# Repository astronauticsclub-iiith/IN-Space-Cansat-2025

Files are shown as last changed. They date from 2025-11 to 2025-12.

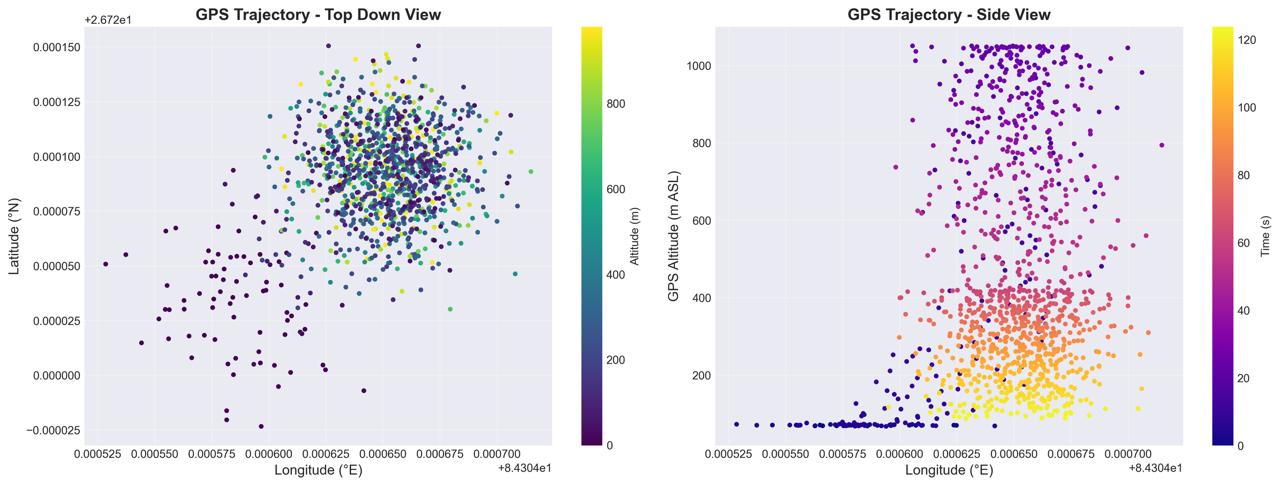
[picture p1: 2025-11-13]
Data-collected/WhatsApp Image 2025-11-07 at 16.43.02_4e6e8e08.jpg

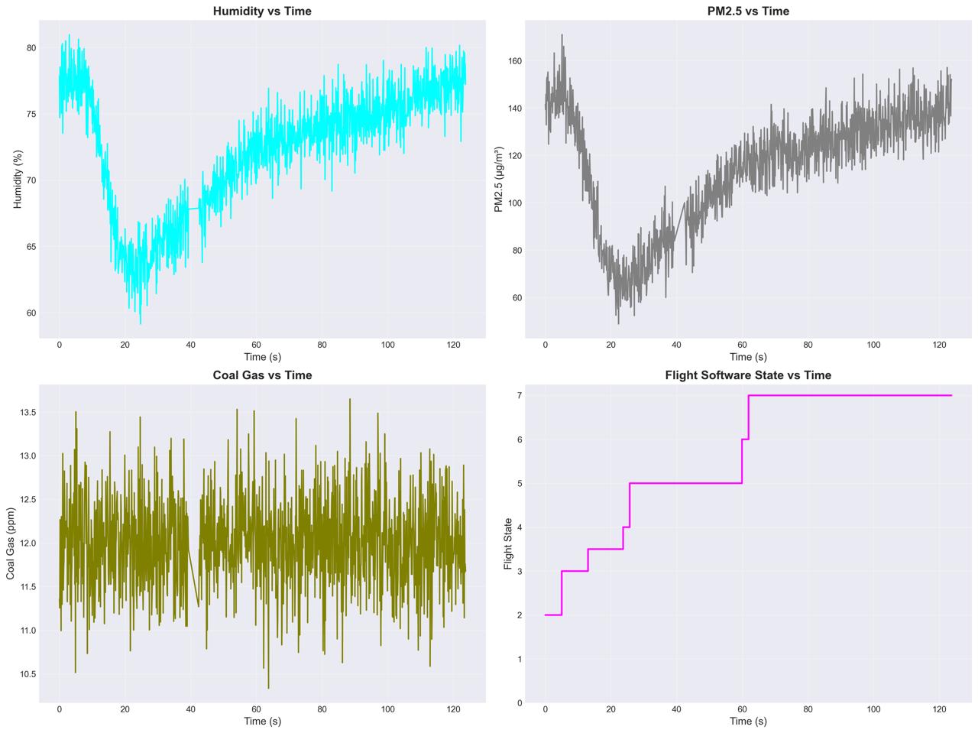
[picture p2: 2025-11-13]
Data-collected/WhatsApp Image 2025-11-07 at 16.43.02_c65afb3b.jpg

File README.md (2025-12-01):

## INSpace CanSat 24-25.

We have open-sourced our codefiles, 3D CAD models, PCB designs and simulation code for future teams participating in team in CanSat or anyone interested. The mission requirements for INSpace CanSat 24-25 be found [here](/Mission_Requirements). The directory structure is mostly self-explanatory.

**Team Name:** Team Brahmand (IIIT Hyderabad)

**Sponsors:** iHub Data (prototyping and development cost), IIIT Hyderabad (travel support)

**Advisor:** Prof Harikumar Kandath and Prof. Kavita Vemuri

**Members:** 
- Harsh Kapoor (Team Lead)
- Madhan Sai Krishna
- Vignesh Vembar
- Vijay Aravynthan S R
- Anushka Sharma
- Tejasvini Ramaswamy

**Additional Contributors:**
- Nav Singhal
- Kandagatla Akshith
- Tatva Agarwal
- Akshat Puneet
- Srinath Dhatre
- Bhaskar Itikela

**Mentors:** Members of Team Wanderlust (represented IIIT Hyderabad in US CanSat 23-24)

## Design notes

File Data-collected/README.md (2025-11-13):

# Data
Data collected during INSPACe CANSAT 2025, please refer to the following table for the units and details -

| **Parameter** | **Description** | **Unit** |
| --- | --- | --- |
| **Time** | Timestamp of the measurement | s |
| **Packet** | Telemetry packet count | — |
| **State** | System or flight state indicator | — |
| **Altitude** | Measured altitude (from barometric sensor) | m |
| **Pressure** | Atmospheric pressure | hPa |
| **Temperature (Barometric)** | Ambient temperature (from BMP sensor) | °C |
| **Temperature (DHT)** | Ambient temperature (from DHT sensor) | °C |
| **Humidity** | Relative humidity | % |
| **Voltage** | System/battery voltage | V |
| **GPS Latitude** | Latitude coordinate | ° |
| **GPS Longitude** | Longitude coordinate | ° |
| **GPS Altitude** | Altitude from GPS module | m |
| **Acceleration (X, Y, Z)** | Linear acceleration components | m/s² |
| **G-Force** | Resultant acceleration magnitude | g |
| **Gyro Rate** | Angular rate (from gyroscope) | °/s |
| **PM2.5** | Particulate matter concentration | µg/m³ |
| **CO (Coal Gas)** | Carbon monoxide concentration | ppm |

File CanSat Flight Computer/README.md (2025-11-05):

# CANSAT_ONBOARD_FINAL

- The CANSAT_ONBOARD_FINAL repository contains the complete flight software for the CanSat competition. This includes sensor integration, state management, telemetry transmission, command handling, data logging, and deployment mechanisms.
- Deployed on ESP32 microcontroller using FreeRTOS for real-time task management.
- Developed in C++ with modular architecture for Arduino IDE compatibility.

## Flows

### State diagram Flow (missing the SHT41)
```mermaid
graph LR
    subgraph Sensors ["Sensor Hardware"]
        LPS22[LPS22<br/>Barometer]
        BME680[BME680<br/>Environmental]
        ICM[ICM-20948<br/>9-DOF IMU]
        GPS[GPS Module<br/>GNSS]
        ADC[ADC<br/>Battery Voltage]
    end
    
    subgraph Processing ["Data Processing"]
        Fusion[Sensor Fusion<br/>Pressure & Temp]
        KF[Kalman Filter<br/>Altitude & Velocity]
        IMUCal[IMU Calibration<br/>Offset Removal]
        BattCalc[Battery %<br/>Calculator]
    end
    
    subgraph Output ["Data Output"]
        TelStruct[Telemetry<br/>Structure]
        CSV[CSV Format]
        LoRaTX[LoRa TX]
        SDLOG[SD Card Log]
    end
    
    LPS22 -->|Pressure, Temp| Fusion
    BME680 -->|Pressure, Temp,<br/>Humidity, Gas| Fusion
    
    Fusion -->|Fused Pressure| KF
    Fusion -->|Fused Temp| TelStruct
    BME680 -->|Humidity| TelStruct
    BME680 -->|Gas Resistance| TelStruct
    
    KF -->|Filtered Altitude| TelStruct
    KF -->|Vertical Velocity| TelStruct
    
    ICM -->|Raw Accel, Gyro| IMUCal
    IMUCal -->|Calibrated IMU| TelStruct
    
    GPS -->|Lat, Lon, Alt,<br/>Time, Sats| TelStruct
    GPS -->|GPS Alt| KF
    
    ADC -->|Raw Voltage| BattCalc
    BattCalc -->|Voltage, %| TelStruct
    
    TelStruct -->|Packet Data| CSV
    CSV -->|Formatted String| LoRaTX
    CSV -->|Formatted String| SDLOG
    
    style Sensors fill:#E8F4F8
    style Processing fill:#FFF4E6
    style Output fill:#E8F5E9
    
    style Fusion fill:#FFD54F
    style KF fill:#4FC3F7
    style IMUCal fill:#81C784
    style LoRaTX fill:#FF8A65
    style SDLOG fill:#BA68C8
```

---

### State Diagram (Syntax error)

```mermaid
stateDiagram-v2
    [*] --> BOOT: Power On
    
    BOOT --> LAUNCH_PAD: All Sensors OK
    BOOT --> BOOT: Waiting for Sensors
    
    LAUNCH_PAD --> TEST_MODE: "CMD: SET_MODE,TEST"
    TEST_MODE --> LAUNCH_PAD: "CMD: SET_MODE,FLIGHT"
    
    LAUNCH_PAD --> ASCENT: Launch Detected<br/>(Accel > 2.5g)
    
    ASCENT --> ROCKET_DEPLOY: Apogee Detected<br/>(V_vertical < -5 m/s)
    ASCENT --> ASCENT: Track Max Altitude
    
    ROCKET_DEPLOY --> DESCENT: Parachute Deployed<br/>(After 2 sec)
    
    DESCENT --> AEROBRAKE_RELEASE: Low Altitude<br/>(Alt < 50m)
    DESCENT --> IMPACT: Impact Detected<br/>(Alt < 5m, V < 2m/s)
    
    AEROBRAKE_RELEASE --> IMPACT: Impact Detected<br/>(Alt < 5m, V < 2m/s)
    
    IMPACT --> [*]: Mission Complete
    
    note right of BOOT
        Initialize all systems
        Load BlackBox state
        Check sensor health
    end note
    
    note right of LAUNCH_PAD
        Wait for launch
        Accept ground commands
        Continuous calibration available
    end note
    
    note right of TEST_MODE
        Manual testing mode
        Servo tests allowed
        No automatic transitions
    end note
    
    note right of ASCENT
        Record max altitude
        Monitor vertical velocity
        Prepare for apogee
    end note
    
    note right of ROCKET_DEPLOY
        Deploy parachute at apogee
        Log deployment event
        Save state to BlackBox
    end note
    
    note right of DESCENT
        Monitor altitude
        Check for release altitude
        Prepare for landing
    end note
    
    note right of AEROBRAKE_RELEASE
        Release aerobrake
        Continue descent monitoring
    end note
    
    note right of IMPACT
        Continue telemetry for recovery
        Reduce transmission rate
        Log GPS coordinates
    end note
```

---

### System Flowchart 
```mermaid
graph TB
    Start([Power On]) --> Init[Initialize System]
    Init --> I2C[Setup I2C Bus]
    I2C --> SPI[Setup SPI Bus]
    SPI --> InitSensors[Initialize Sensors]
    
    InitSensors --> CheckLPS{LPS22 OK?}
    CheckLPS -->|Yes| CheckBME{BME680 OK?}
    CheckLPS -->|No| LogLPSFail[Log LPS22 Failure]
    LogLPSFail --> CheckBME
    
    CheckBME -->|Yes| CheckIMU{ICM-20948 OK?}
    CheckBME -->|No| LogBMEFail[Log BME680 Failure]
    LogBMEFail --> CheckIMU
    
    CheckIMU -->|Yes| CheckLoRa{LoRa OK?}
    CheckIMU -->|No| LogIMUFail[Log IMU Failure]
    LogIMUFail --> CheckLoRa
    
    CheckLoRa -->|Yes| CheckGPS{GPS OK?}
    CheckLoRa -->|No| LogLoRaFail[Log LoRa Failure]
    LogLoRaFail --> CheckGPS
    
    CheckGPS -->|Yes| CheckServo{Servo OK?}
    CheckGPS -->|No| LogGPSFail[Log GPS Failure]
    LogGPSFail --> CheckServo
    
    CheckServo -->|Yes| CheckSD{SD Card OK?}
    CheckServo -->|No| LogServoFail[Log Servo Failure]
    LogServoFail --> CheckSD
    
    CheckSD -->|Yes| LoadState[BlackBox: Load Previous State]
    CheckSD -->|No| LogSDFail[Log SD Failure]
    LogSDFail --> LoadState
    
    LoadState --> RecoveryCheck{Valid Recovery Data?}
    RecoveryCheck -->|Yes| RecoverState[Recover Flight State]
    RecoveryCheck -->|No| FreshBoot[Fresh Boot Detected]
    
    RecoverState --> CreateTasks[Create RTOS Tasks]
    FreshBoot --> Calibrate[Calibrate Sensors]
    Calibrate --> CreateTasks
    
    CreateTasks --> Task1[Sensor Task - Core 0, P2]
    CreateTasks --> Task2[Telemetry Task - Core 0, P1]
    CreateTasks --> Task3[Command Task - Core 1, P1]
    CreateTasks --> Task4[State Machine Task - Core 1, P2]
    CreateTasks --> Task5[SD Writer Task - Core 0, P0]
    
    Task1 --> SensorLoop((Sensor Loop))
    Task2 --> TelemetryLoop((Telemetry Loop))
    Task3 --> CommandLoop((Command Loop))
    Task4 --> StateMachine((State Machine))
    Task5 --> SDLoop((SD Writer Loop))
    
    style Start fill:#90EE90
    style Init fill:#87CEEB
    style CreateTasks fill:#FFD700
    style SensorLoop fill:#FF6B6B
    style TelemetryLoop fill:#4ECDC4
    style CommandLoop fill:#95E1D3
    style StateMachine fill:#F38181
    style SDLoop fill:#AA96DA
```

---

# CANSAT Flight Software Requirements Specification

## 1. Functional Requirements

### 1.1 State Management (REQ-FSM)
- **REQ-FSM-001**: System SHALL maintain 8 distinct flight states: BOOT, TEST_MODE, LAUNCH_PAD, ASCENT, ROCKET_DEPLOY, DESCENT, AEROBRAKE_RELEASE, IMPACT
- **REQ-FSM-002**: Current state SHALL be transmitted in every telemetry packet
- **REQ-FSM-003**: System SHALL recover correct state after processor reset using sensor data
- **REQ-FSM-004**: State transitions SHALL be logged with timestamp
- **REQ-FSM-005**: Invalid state transitions SHALL be prevented

### 1.2 Telemetry Requirements (REQ-TM)
- **REQ-TM-001**: Telemetry SHALL be transmitted at 1 Hz minimum
- **REQ-TM-002**: Telemetry packet SHALL follow CSV format specified in competition rules
- **REQ-TM-003**: Telemetry SHALL include all 16 required fields: TEAM_ID, TIME_STAMPING, PACKET_COUNT, ALTITUDE, PRESSURE, TEMP, VOLTAGE, GNSS_TIME, GNSS_LATITUDE, GNSS_LONGITUDE, GNSS_ALTITUDE, GNSS_SATS, ACCEL_DATA, GYRO_DATA, FLIGHT_STATE, OPTIONAL_DATA
- **REQ-TM-004**: Time resolution SHALL be 1 second or better
- **REQ-TM-005**: Timestamp SHALL NOT be affected by processor reset
- **REQ-TM-006**: Packet count SHALL persist across resets
- **REQ-TM-007**: Altitude SHALL be relative to ground with 0.1m resolution
- **REQ-TM-008**: Pressure SHALL be in Pascals with 1 Pa resolution
- **REQ-TM-009**: Temperature SHALL be in Celsius with 0.1°C resolution
- **REQ-TM-010**: Voltage SHALL be in Volts with 0.01V resolution
- **REQ-TM-011**: GNSS coordinates SHALL have 0.0001 degree resolution
- **REQ-TM-012**: Accelerometer data SHALL be in m/s²
- **REQ-TM-013**: Gyroscope data SHALL be in deg/s
- **REQ-TM-014**: Optional data SHALL include battery percentage and vertical speed

### 1.3 Sensor Requirements (REQ-SENS)
- **REQ-SENS-001**: System SHALL read LPS22 barometer at 10 Hz minimum
- **REQ-SENS-002**: System SHALL read BME680 environmental sensor at 1 Hz minimum
- **REQ-SENS-003**: System SHALL read ICM-20948 IMU at 10 Hz minimum
- **REQ-SENS-004**: System SHALL read SHT41 temperature/humidity sensor at 1 Hz minimum
- **REQ-SENS-005**: System SHALL parse GPS data continuously without blocking
- **REQ-SENS-006**: Barometric altitude SHALL use sensor fusion from LPS22 and BME680
- **REQ-SENS-007**: Temperature SHALL use sensor fusion from LPS22 and BME680
- **REQ-SENS-008**: GPS altitude SHALL be used for cross-validation only
- **REQ-SENS-009**: Sensor failures SHALL be detected and logged
- **REQ-SENS-009**: System SHALL continue operating with degraded sensor suite
- **REQ-SENS-010**: Altitude SHALL be filtered using Kalman filter

### 1.4 Calibration Requirements (REQ-CAL)
- **REQ-CAL-001**: Ground altitude SHALL be calibrated before launch
- **REQ-CAL-002**: IMU gyroscope offsets SHALL be calibrated on launch pad
- **REQ-CAL-003**: Calibration SHALL use minimum 50 samples
- **REQ-CAL-004**: Calibration SHALL be triggerable via ground command
- **REQ-CAL-005**: Calibration results SHALL be logged

### 1.5 Command & Control Requirements (REQ-CMD)
- **REQ-CMD-001**: System SHALL receive commands via LoRa
- **REQ-CMD-002**: System SHALL support CAL_ALT command for altitude calibration
- **REQ-CMD-003**: System SHALL support CAL_IMU command for IMU calibration
- **REQ-CMD-004**: System SHALL support RESET_STATE command
- **REQ-CMD-005**: System SHALL support STATUS command for health check
- **REQ-CMD-006**: System SHALL support SET_MODE,TEST command
- **REQ-CMD-007**: System SHALL support SET_MODE,FLIGHT command
- **REQ-CMD-008**: System SHALL support TEST_SERVO command (ground only)
- **REQ-CMD-009**: System SHALL support DEPLOY_TEST command (ground only)
- **REQ-CMD-010**: System SHALL support START_TX/STOP_TX commands
- **REQ-CMD-011**: Unknown commands SHALL be rejected and logged
- **REQ-CMD-012**: Commands SHALL be processed within 100ms

### 1.6 Data Logging Requirements (REQ-LOG)
- **REQ-LOG-001**: All telemetry SHALL be logged to SD card
- **REQ-LOG-002**: All events SHALL be logged to separate event file
- **REQ-LOG-003**: Log files SHALL use CSV format
- **REQ-LOG-004**: Log files SHALL include headers
- **REQ-LOG-005**: Log filename SHALL include team ID and sequence number
- **REQ-LOG-006**: SD card writes SHALL be buffered to prevent data loss
- **REQ-LOG-007**: Buffers SHALL flush every 5 seconds
- **REQ-LOG-008**: System SHALL continue if SD card fails

### 1.7 Deployment Requirements (REQ-DEPLOY)
- **REQ-DEPLOY-001**: Parachute SHALL deploy at apogee detection
- **REQ-DEPLOY-002**: Apogee detection SHALL use vertical velocity < -5 m/s
- **REQ-DEPLOY-003**: Apogee detection SHALL require 3 seconds in ascent
- **REQ-DEPLOY-004**: Aerobrake SHALL release below 50m altitude
- **REQ-DEPLOY-005**: Deployment commands SHALL be mutex-protected
- **REQ-DEPLOY-006**: Deployment events SHALL be logged to BlackBox
- **REQ-DEPLOY-007**: Manual deployment SHALL only work on ground

### 1.8 Launch Detection Requirements (REQ-LAUNCH)
- **REQ-LAUNCH-001**: Launch SHALL be detected by acceleration > 2.5g
- **REQ-LAUNCH-002**: Launch detection SHALL require 2 seconds on pad
- **REQ-LAUNCH-003**: Launch event SHALL be logged
- **REQ-LAUNCH-004**: Launch SHALL transition to ASCENT state

### 1.9 Landing Detection Requirements (REQ-LAND)
- **REQ-LAND-001**: Landing SHALL be detected by altitude < 5m AGL
- **REQ-LAND-002**: Landing SHALL be detected by vertical speed < 2 m/s
- **REQ-LAND-003**: Landing detection SHALL require 10 seconds in descent
- **REQ-LAND-004**: Landing SHALL transition to IMPACT state
- **REQ-LAND-005**: Post-landing telemetry SHALL continue for recovery

### 1.10 Recovery Requirements (REQ-RECOVERY)
- **REQ-RECOVERY-001**: System SHALL save state to NVS every 5 seconds
- **REQ-RECOVERY-002**: System SHALL save state before critical operations
- **REQ-RECOVERY-003**: System SHALL load previous state on boot
- **REQ-RECOVERY-004**: System SHALL validate loaded state with magic number
- **REQ-RECOVERY-005**: System SHALL determine correct state from sensor data
- **REQ-RECOVERY-006**: Recovery SHALL be logged
- **REQ-RECOVERY-007**: Fresh boot SHALL be detected and logged

### 1.11 Safety Requirements (REQ-SAFE)
- **REQ-SAFE-001**: All SPI operations SHALL be mutex-protected
- **REQ-SAFE-002**: All servo operations SHALL be mutex-protected
- **REQ-SAFE-003**: All SD operations SHALL be mutex-protected
- **REQ-SAFE-004**: Battery voltage SHALL be monitored continuously
- **REQ-SAFE-005**: Low battery SHALL be logged (< 10%)
- **REQ-SAFE-006**: Sensor outliers SHALL be detected and rejected
- **REQ-SAFE-007**: Watchdog timer SHALL be implemented

## 2. Performance Requirements

### 2.1 Timing (REQ-PERF-TIME)
- **REQ-PERF-TIME-001**: Telemetry transmission SHALL occur every 1000ms ±50ms
- **REQ-PERF-TIME-002**: Sensor reading SHALL occur every 100ms ±10ms
- **REQ-PERF-TIME-003**: State machine SHALL execute every 100ms
- **REQ-PERF-TIME-004**: Command processing SHALL occur within 100ms
- **REQ-PERF-TIME-005**: Servo response SHALL occur within 200ms

### 2.2 Memory (REQ-PERF-MEM)
- **REQ-PERF-MEM-001**: Heap usage SHALL NOT exceed 80% of available
- **REQ-PERF-MEM-002**: Stack usage per task SHALL NOT exceed 4KB
- **REQ-PERF-MEM-003**: Telemetry buffer SHALL hold minimum 20 packets
- **REQ-PERF-MEM-004**: Event buffer SHALL hold minimum 20 events

### 2.3 Accuracy (REQ-PERF-ACC)
- **REQ-PERF-ACC-001**: Altitude accuracy SHALL be ±2m after filtering
- **REQ-PERF-ACC-002**: Vertical velocity accuracy SHALL be ±0.5 m/s
- **REQ-PERF-ACC-003**: Temperature fusion SHALL reduce noise by 50%
- **REQ-PERF-ACC-004**: Pressure fusion SHALL reduce noise by 40%

## 3. Interface Requirements

### 3.1 Hardware Interfaces (REQ-HW)
- **REQ-HW-001**: LPS22 SHALL communicate via I2C at address 0x5D
- **REQ-HW-002**: BME680 SHALL communicate via I2C at address 0x76
- **REQ-HW-003**: ICM-20948 SHALL communicate via I2C at address 0x69
- **REQ-HW-004**: LoRa SHALL use SPI with CS on GPIO 5
- **REQ-HW-005**: SD card SHALL use SPI with CS on GPIO 15
- **REQ-HW-006**: GPS SHALL use UART2 (RX:16, TX:17) at 9600 baud
- **REQ-HW-007**: Servo SHALL use PWM on GPIO 13
- **REQ-HW-008**: Battery voltage SHALL be read on GPIO 34 (ADC)

### 3.2 Communication Interfaces (REQ-COMM)
- **REQ-COMM-001**: LoRa SHALL operate at 433 MHz
- **REQ-COMM-002**: LoRa SHALL use spreading factor 7
- **REQ-COMM-003**: LoRa SHALL use bandwidth 125 kHz
- **REQ-COMM-004**: LoRa SHALL use coding rate 4/5
- **REQ-COMM-005**: LoRa SHALL enable CRC checking
- **REQ-COMM-006**: Serial debug SHALL operate at 115200 baud

## 4. Software Architecture Requirements

### 4.1 Task Structure (REQ-ARCH-TASK)
- **REQ-ARCH-TASK-001**: System SHALL use FreeRTOS
- **REQ-ARCH-TASK-002**: Sensor reading SHALL run on Core 0, Priority 2
- **REQ-ARCH-TASK-003**: Telemetry SHALL run on Core 0, Priority 1
- **REQ-ARCH-TASK-004**: Command processing SHALL run on Core 1, Priority 1
- **REQ-ARCH-TASK-005**: State machine SHALL run on Core 1, Priority 2
- **REQ-ARCH-TASK-006**: SD writing SHALL run on Core 0, Priority 0

### 4.2 Modularity (REQ-ARCH-MOD)
- **REQ-ARCH-MOD-001**: Configuration SHALL be in separate config.h
- **REQ-ARCH-MOD-002**: Sensor code SHALL be in sensors.h
- **REQ-ARCH-MOD-003**: Telemetry code SHALL be in Telemetry.h
- **REQ-ARCH-MOD-004**: State recovery SHALL be in BlackBox.h
- **REQ-ARCH-MOD-005**: Filtering SHALL be in KalmanFilter.h
- **REQ-ARCH-MOD-006**: Sensor fusion SHALL be in SensorFusion.h

## 5. Test Requirements

### 5.1 Unit Tests (REQ-TEST-UNIT)
- **REQ-TEST-UNIT-001**: Kalman filter SHALL be unit tested
- **REQ-TEST-UNIT-002**: Sensor fusion SHALL be unit tested
- **REQ-TEST-UNIT-003**: State transitions SHALL be unit tested
- **REQ-TEST-UNIT-004**: CSV formatting SHALL be unit tested
- **REQ-TEST-UNIT-005**: BlackBox recovery SHALL be unit tested

### 5.2 Integration Tests (REQ-TEST-INT)
- **REQ-TEST-INT-001**: All sensors SHALL be tested together
- **REQ-TEST-INT-002**: Command reception SHALL be tested
- **REQ-TEST-INT-003**: Telemetry transmission SHALL be tested
- **REQ-TEST-INT-004**: SD logging SHALL be tested
- **REQ-TEST-INT-005**: Servo control SHALL be tested

### 5.3 System Tests (REQ-TEST-SYS)
- **REQ-TEST-SYS-001**: Launch detection SHALL be tested in simulation
- **REQ-TEST-SYS-002**: Apogee detection SHALL be tested in simulation
- **REQ-TEST-SYS-003**: Landing detection SHALL be tested in simulation
- **REQ-TEST-SYS-004**: Reset recovery SHALL be tested
- **REQ-TEST-SYS-005**: Full flight profile SHALL be simulated

## 6. Compliance Requirements

### 6.1 Competition Rules (REQ-COMP)
- **REQ-COMP-001**: Telemetry format SHALL match competition specification exactly
- **REQ-COMP-002**: CSV file SHALL be named Flight_<TEAM_ID>.csv
- **REQ-COMP-003**: All required fields SHALL be present
- **REQ-COMP-004**: SI units SHALL be used for all measurements
- **REQ-COMP-005**: Ground station SHALL be able to parse telemetry

---

## Requirement Traceability Matrix

| Requirement ID | Verification Method | Test Case | Priority |
|---|---|---|---|
| REQ-FSM-001 | Code Review + Test | TC-001 | Critical |
| REQ-FSM-002 | Unit Test | TC-002 | Critical |
| REQ-FSM-003 | System Test | TC-003 | Critical |
| REQ-TM-001 | Timing Test | TC-004 | Critical |
| REQ-TM-002 | Format Test | TC-005 | Critical |
| REQ-SENS-001 | Performance Test | TC-006 | High |
| REQ-SENS-005 | Unit Test | TC-007 | High |
| REQ-CAL-001 | Integration Test | TC-008 | High |
| REQ-CMD-001 | Integration Test | TC-009 | High |
| REQ-LOG-001 | System Test | TC-010 | High |
| REQ-DEPLOY-001 | System Test | TC-011 | Critical |
| REQ-LAUNCH-001 | Simulation Test | TC-012 | Critical |
| REQ-LAND-001 | Simulation Test | TC-013 | Critical |
| REQ-RECOVERY-001 | System Test | TC-014 | Critical |
| REQ-SAFE-001 | Code Review | TC-015 | Critical |

---

## References 
Good playlist for FreeRTOS: https://www.youtube.com/watch?v=kP-pP6FEu8I&list=PLzvRQMJ9HDiQ3OIuBWCEW6yE0S0LUWhGU&index=20

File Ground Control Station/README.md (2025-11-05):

# GCS - By VA
# OLD VERSION (Don't use)
- new version is not public due to reasons 🙃
  
## Three main components
- Next js based 3d dashboard
- Fast API python program (reads from serial, saves data to csv and exposes an API endpoint for dashboard)
- ESP32 LoRa / Xbee parser

## Things to do 
- [x] Componentize the dashboard
- [x] Model replace ([3d convert] https://github.com/pmndrs/gltfjsx)
- [x] Serial read
- [x] CSV write
- [x] Faster updates
- [x] UI / UX improvements
- [x] Audio cues
- [x] Music ??? (After landing, what song?? Thunderstruck??)

## Images
### Dark Mode
GCS Dark

### Lite Mode
GCS Lite

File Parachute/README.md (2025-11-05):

# Backup-Parachute-System

A quad-redundant parachute deployment system for CanSat missions, designed to run on the Seeeduino XIAO (SAMD21).

## Overview

This system provides four independent deployment triggers to ensure reliable parachute deployment under various failure scenarios. Uses onboard clock and BMP280 pressure sensor for fault-tolerant operation.

## Hardware Requirements

- **Microcontroller:** Seeeduino XIAO SAMD21
- **Sensor:** Adafruit BMP280 (I2C address: 0x76)
- **Actuator:** Standard servo motor (connected to pin A1)
- **Power:** Appropriate power supply for XIAO and servo

## Wiring

| Component | Pin |
|---|-----|
| Servo Signal | A1 |
| BMP280 SDA | SDA (I2C) |
| BMP280 SCL | SCL (I2C) 


## Deployment Logic

The system uses a **quad-redundant trigger mechanism**. The first condition met triggers the servo to deploy the parachute.

### Deployment Triggers

1. **Primary: Altitude-Based Descent 🏔️**
   - **Condition:** After passing **500m**, deploys when altitude drops below **450m** for **5 consecutive readings**
   - **Purpose:** Primary deployment mechanism based on altitude thresholds
   - **Debounce:** 5 readings (1 second at 200ms sampling rate)

2. **Secondary: Post-Apogee Timer ⏱️**
   - **Condition:** Deploys **1 minute** after apogee (peak altitude) is detected
   - **Purpose:** Backup if altitude sensor fails during descent
   - **Detection:** Apogee detected when altitude drops 2m below maximum

3. **Tertiary: Master System Timer 🚨**
   - **Condition:** Deploys **30 seconds** after power-on (configurable to 10 minutes for flight)
   - **Purpose:** Ultimate failsafe for catastrophic failures
   - **Note:** Currently set to 30s for testing; change to `10 * 60 * 1000UL` for actual flight

4. **Quaternary: Emergency Low-Altitude Descent 🆘**
   - **Condition:** Descending for **>10 consecutive readings** while below **100m**
   - **Purpose:** Emergency deployment if stuck in tumbling descent at low altitude
   - **Reset:** Counter resets if altitude increases

## Features

- **Servo Self-Test:** On startup, servo sweeps full range (0° → 90° → 0°) to verify mechanical operation
- **Ground-Level Calibration:** Automatically calibrates pressure at startup for accurate altitude readings
- **Serial Debugging:** Real-time altitude, arming status, and timer information via Serial Monitor (9600 baud)
- **Single Deployment:** Prevents multiple deployments once triggered

## Installation

1. Install required libraries in Arduino IDE:
   ```
   - Adafruit BMP280 Library
   - Adafruit Unified Sensor
   - Servo (built-in)
   ```

2. Connect hardware according to wiring diagram

3. Upload code to Seeeduino XIAO

4. Open Serial Monitor (9600 baud) to view system status

## Configuration

### Key Parameters (adjust in code as needed)

```cpp
const float MIN_APOGEE_ALTITUDE = 500.0;        // Arming altitude (meters)
const float DEPLOYMENT_ALTITUDE = 450.0;        // Primary deployment altitude (meters)
const float EMERGENCY_LOW_ALTITUDE = 100.0;     // Emergency trigger altitude (meters)
const int DESCENT_READINGS_REQUIRED = 5;        // Debounce for primary trigger
const int EMERGENCY_DESCENT_READINGS = 10;      // Debounce for emergency trigger
const unsigned long APOGEE_TIMER_MS = 60000;    // Post-apogee timeout (1 minute)
const unsigned long MASTER_TIMER_MS = 30000;    // Master failsafe (30 sec for testing)
```

### Servo Angles

```cpp
const int SERVO_CLOSED_ANGLE = 0;   // Parachute locked
const int SERVO_OPEN_ANGLE = 90;    // Parachute deployed
```

## Testing

### Ground Test Mode
Current configuration deploys after 30 seconds for quick testing. Before flight:

**⚠️ CRITICAL: Change master timer back to 10 minutes:**
```cpp
const unsigned long MASTER_TIMER_MS = 10 * 60 * 1000UL;
```

### Expected Serial Output (Ground)
```
Alt: 0.1m, Max: 0.2m, Armed: 0, Master Time: 5s
Alt: 0.1m, Max: 0.2m, Armed: 0, Master Time: 6s
...
```

### Expected Serial Output (Flight)
```
Alt: 523.4m, Max: 523.4m, Armed: 1, Master Time: 45s
!!! APOGEE DETECTED - Starting 1-minute backup timer. !!!
Alt: 518.2m, Max: 523.4m, Armed: 1, Apogee Timer: 3s, Master Time: 48s
...
**************************************
DEPLOYING PARACHUTE! Reason: Altitude Trigger (Confirmed Descent)
**************************************
```

## Safety Notes

- Always test servo operation before flight
- Verify BMP280 sensor readings are stable
- Ensure backup battery is fully charged
- Test deployment mechanism separately before integration
- **Remember to adjust timer back to 10 minutes for actual flight**

## Troubleshooting

| Issue | Solution |
|---|---|
| Servo doesn't move | Check power supply, verify pin A1 connection |
| BMP280 not found | Verify I2C address (0x76 vs 0x77), check wiring |
| Deploys immediately | Check master timer value, verify startTime initialization |
| Altitude readings unstable | Sensor may need settling time, increase filter settings |

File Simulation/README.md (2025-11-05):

# CanSat-Simulation

- ROS 2 Humble + Gazebo (Classic, Fortress)  
- Mujoco  
- OpenFoam
- OpenRocket
- KiCAD

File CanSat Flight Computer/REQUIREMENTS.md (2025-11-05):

# CanSat Requirements Specification

## Overview
This document outlines the complete requirements for the CanSat flight software system, covering all functional, performance, safety, and interface requirements.

## Flight State Machine Requirements

### REQ-FSM-001: Flight States Definition
**Description:** The system shall implement exactly 8 flight states
**States:**
- BOOT = 0 (System initialization)
- TEST_MODE = 1 (Ground testing mode)  
- LAUNCH_PAD = 2 (Ready for launch)
- ASCENT = 3 (Rocket powered flight)
- ROCKET_DEPLOY = 4 (CanSat deployment from rocket)
- DESCENT = 5 (Parachute descent)
- AEROBRAKE_RELEASE = 6 (Aerobrake deployment)
- IMPACT = 7 (Ground contact and recovery)

## Telemetry Requirements

### REQ-TM-001: Transmission Rate
**Description:** Telemetry shall be transmitted at 1 Hz (once per second)
**Verification:** Check TELEMETRY_INTERVAL = 1000ms

### REQ-TM-002: CSV Format
**Description:** All telemetry shall use competition-specified CSV format
**Format:** TEAM_ID,TIME,PACKET_COUNT,ALTITUDE,PRESSURE,TEMP,VOLTAGE,GNSS_TIME,GNSS_LAT,GNSS_LON,GNSS_ALT,GNSS_SATS,ACCEL_DATA,GYRO_DATA,STATE,OPTIONAL_DATA

### REQ-TM-003: Required Fields
**Description:** All 16 telemetry fields must be present in every packet
1. TEAM_ID - Team identifier string
2. TIME_STAMPING - Mission elapsed time
3. PACKET_COUNT - Sequential packet number  
4. ALTITUDE - Pressure altitude (m)
5. PRESSURE - Atmospheric pressure (Pa)
6. TEMP - Temperature (°C)
7. VOLTAGE - Battery voltage (V)
8. GNSS_TIME - GPS time string
9. GNSS_LATITUDE - GPS latitude (degrees)
10. GNSS_LONGITUDE - GPS longitude (degrees) 
11. GNSS_ALTITUDE - GPS altitude (m)
12. GNSS_SATS - Number of GPS satellites
13. ACCELEROMETER_DATA - 3-axis acceleration
14. GYRO_SPIN_RATE - 3-axis gyro data
15. FLIGHT_SOFTWARE_STATE - Current flight state
16. OPTIONAL_DATA - Additional sensor data

### REQ-TM-008 to REQ-TM-013: Data Resolution
- **REQ-TM-008:** Altitude resolution: 0.1 meters
- **REQ-TM-009:** Pressure resolution: 1 Pa  
- **REQ-TM-010:** Temperature resolution: 0.1°C
- **REQ-TM-011:** Voltage resolution: 0.01V
- **REQ-TM-012:** GPS coordinate resolution: 0.0001 degrees
- **REQ-TM-013:** Time resolution: 0.1 seconds

## Sensor Requirements

### REQ-SENS-001: Pressure Sensors
**Description:** System shall use dual pressure sensors for redundancy
**Sensors:** LPS22HB primary, BME680 secondary

### REQ-SENS-002: IMU Requirements  
**Description:** 9-DOF IMU for attitude and acceleration
**Sensor:** ICM-20948 (3-axis accel, gyro, magnetometer)

### REQ-SENS-003: GPS Requirements
**Description:** GPS receiver for position and time
**Requirements:** Minimum 4 satellites for valid fix

### REQ-SENS-004: Environmental Sensors
**Description:** Temperature, humidity, gas resistance monitoring
**Sensor:** BME680 for environmental data

### REQ-SENS-005: Sensor Fusion
**Description:** Multiple sensors fused for improved accuracy
**Implementation:** Kalman filtering and sensor health monitoring

### REQ-SENS-006: Sensor Health Monitoring
**Description:** Continuous monitoring of sensor status
**Actions:** Automatic fallback to backup sensors

## Flight Detection Requirements

### REQ-LAUNCH-001: Launch Detection
**Description:** Detect rocket launch via acceleration threshold
**Threshold:** 2.5g sustained acceleration
**Duration:** Minimum 100ms above threshold

### REQ-DEPLOY-002: Apogee Detection  
**Description:** Detect CanSat deployment from rocket
**Method:** Vertical velocity < -5 m/s (descent initiated)
**Backup:** Altitude decrease over 3 consecutive readings

### REQ-LAND-001: Impact Detection - Altitude
**Description:** Detect ground impact via altitude threshold
**Threshold:** Below 5 meters AGL (Above Ground Level)

### REQ-LAND-002: Impact Detection - Velocity
**Description:** Confirm landing via low vertical velocity
**Threshold:** Vertical velocity < 2 m/s for 5 seconds

## Command Interface Requirements

### REQ-CMD-001 to REQ-CMD-010: Ground Commands
**Description:** System shall respond to ground station commands
**Commands:**
1. **CMD,CAL_ALT** - Calibrate ground altitude reference
2. **CMD,CAL_IMU** - Calibrate IMU sensors
3. **CMD,RESET_STATE** - Reset flight state to LAUNCH_PAD
4. **CMD,STATUS** - Report current system status
5. **CMD,SET_MODE,TEST** - Enter test mode
6. **CMD,SET_MODE,FLIGHT** - Enter flight mode  
7. **CMD,TEST_SERVO** - Test servo operation
8. **CMD,DEPLOY_TEST** - Test deployment mechanism
9. **CMD,START_TX** - Enable telemetry transmission
10. **CMD,STOP_TX** - Disable telemetry transmission

## Performance Requirements

### REQ-PERF-TIME-001: Telemetry Timing
**Description:** Telemetry transmitted every 1000ms ±50ms
**Jitter:** Maximum 5% timing deviation

### REQ-PERF-TIME-002: Sensor Reading Rate  
**Description:** Sensors read at 10 Hz (100ms intervals)
**Critical:** No missed sensor readings during flight

### REQ-PERF-MEM-001: Memory Usage
**Description:** Total firmware size < 80% of available flash
**Flash:** ESP32 4MB flash, firmware < 3.2MB
**RAM:** Runtime RAM usage < 70% of available

### REQ-PERF-POWER-001: Power Management
**Description:** System operational for minimum 3 hours
**Battery:** Monitor and report battery voltage
**Sleep:** Low-power modes when appropriate

## Safety Requirements

### REQ-SAFE-001: Dual Sensors
**Description:** Critical measurements use redundant sensors
**Implementation:** Primary/backup sensor pairs

### REQ-SAFE-002: Watchdog Timer
**Description:** Hardware watchdog prevents system lockup
**Timeout:** 5-second watchdog timer

### REQ-SAFE-003: Mutex Protection
**Description:** Shared resources protected by mutexes
**Resources:** SPI bus, I2C bus, SD card, servo control

### REQ-SAFE-004: Error Recovery
**Description:** System recovers from sensor failures
**Actions:** Automatic sensor switching, error logging

### REQ-SAFE-005: Deployment Safety
**Description:** Parachute deployment only in valid states
**States:** Only deploy in DESCENT or AEROBRAKE_RELEASE

## Recovery Requirements

### REQ-RECOVERY-001: BlackBox Logging
**Description:** All critical events logged to non-volatile storage
**Storage:** SD card with backup to EEPROM
**Data:** Flight state changes, sensor failures, commands

### REQ-RECOVERY-002: State Persistence
**Description:** Flight state preserved across power cycles
**Implementation:** State saved to EEPROM every transition
**Recovery:** Automatic state recovery on boot

### REQ-RECOVERY-003: Data Integrity
**Description:** Logged data protected against corruption
**Methods:** Checksums, magic numbers, redundant storage

## Architecture Requirements

### REQ-ARCH-MOD: Modular Design
**Description:** Software organized in functional modules
**Modules:** Config, Sensors, Telemetry, BlackBox, KalmanFilter, SensorFusion, DataBuffer

### REQ-ARCH-TASK: RTOS Task Structure
**Description:** FreeRTOS tasks for concurrent operation
**Tasks:**
- sensorTask (Core 0) - Sensor data collection
- telemetryTask (Core 1) - Data transmission  
- commandTask (Core 1) - Command processing
- stateTask (Core 0) - State machine management
- sdTask (Core 0) - Data logging

### REQ-ARCH-CORE: Dual Core Usage
**Description:** Utilize both ESP32 cores efficiently  
**Core 0:** Time-critical sensor and control tasks
**Core 1:** Communication and data processing

## Hardware Interface Requirements

### REQ-HW-001 to REQ-HW-005: Pin Assignments
**Description:** Standardized pin assignments for hardware interfaces
**Pins:**
- LORA_SS_PIN = 5 (LoRa SPI select)
- GPS_RX_PIN = 16, GPS_TX_PIN = 17 (GPS UART)
- SERVO_PIN = 13 (Parachute servo control)
- VOLTAGE_PIN = 34 (Battery voltage ADC)
- SD_CS_PIN = 15 (SD card SPI select)

### REQ-HW-I2C: I2C Bus Configuration
**Description:** I2C sensors on shared bus with proper addressing
**Addresses:** LPS22=0x5D, BME680=0x76, ICM=0x69, OLED=0x3C

### REQ-HW-SPI: SPI Bus Configuration  
**Description:** SPI devices with proper chip select management
**Devices:** LoRa radio, SD card (separate CS pins)

## Verification Methods
- **Static Analysis:** Code inspection and automated checks
- **Unit Testing:** Individual module testing with mocks
- **Integration Testing:** Module interaction validation  
- **Hardware-in-Loop:** Testing with actual sensors
- **Flight Simulation:** Complete mission scenario testing
- **Ground Testing:** Pre-flight validation procedures

## Compliance Matrix
All requirements are traceable to:
- Competition rules and regulations
- Safety standards and best practices  
- Hardware capabilities and constraints
- Mission success criteria

---
**Document Version:** 1.0
**Last Updated:** October 2025
**Approved By:** Team Brahmand

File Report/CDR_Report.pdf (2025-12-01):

# INDEX

## 4. Systems Overview | 4-10

## 5. Mechanical Subsystem | 11-18

## 6. Communications & Data Handling Subsystem | 19-33

## 7. Sensor Subsystem | 34-70

## 8. Actuator Subsystem | 71-72

## 9. Payload/Gyroscope Subsystem | 73-77

## 10. Descent Control Subsystem | 78-79

## 11. Electrical Power Subsystem | 80 - 85

## 12. Flight Software & Ground Control Software Subsystem | 86 - 98

## 13. Mission Operation & Analysis | 99 - 106

## 14. Management & Logistics | 107 - 119

# 1 Introduction

The INSPACe CANSAT Competition serves as a platform for aspiring engineers, scientists, and space enthusiasts to apply

their technical knowledge in a practical, real-world aerospace challenge. This competition fosters innovation, collaboration, and

problem-solving by tasking teams with designing, building, and launching a miniature satellite, or CANSAT, to meet a set of

mission objectives.

This Complete Design Review (CDR) Document encapsulates our team’s design, development, and testing processes. It

serves as a comprehensive record of our mission objectives, system architecture, payload design, electronics integration, software

development, and flight readiness. The document also details the challenges encountered, the solutions implemented, and the

validation methods used to ensure a successful mission.

Our approach to the CANSAT design prioritizes functionality, reliability, and innovation while adhering to the competition

guidelines. Each subsystem has been meticulously designed and tested to ensure optimal performance in the demanding conditions

of launch and recovery. Additionally, we have emphasized teamwork and interdisciplinary collaboration, ensuring that our final

product is a well-engineered solution that meets the expectations of the competition.

Through this journey, we have gained invaluable insights into aerospace engineering, mission planning, and systems engi-

neering. This document not only reflects our technical expertise but also showcases our passion for space exploration and our

commitment to learning. We look forward to contributing to the broader scientific community and leveraging this experience

for future advancements in aerospace technology.

Regards,

Team Brahmand,

IIIT-Hyderabad

# 2 Team Description

# 3 List of Acronyms

Acronym | Full Form | Acronym | Full Form
CANSAT | Can Satellite | INSPACe | Indian National Space Promotion and Authorization Center
GPS | Global Positioning System | IMU | Inertial Measurement Unit
PCB | Printed Circuit Board | RF | Radio Frequency
ADC | Analog to Digital Converter | MCU | Microcontroller Unit
PWM | Pulse Width Modulation | ISP | In-System Programming
FSW | Flight Software | GCS | Ground Control Station
LEO | Low Earth Orbit | EMI | Electromagnetic Interference
RCS | Reaction Control System | SLA | Stereo Lithography Apparatus
CONOPS | Concept of Operations | VHF | Very High Frequency
Li-Po | Lithium Polymer (Battery) | ESC | Electronic Speed Controller
A | Ampere | m | meter
°C | Celsius | mA | Milli-Ampere
dBi | decibel | mm | milli meter
g | Acceleration due to gravity | mW | milli Watt
G | G-force | MB | Mega Byte
GHz | Giga-Hertz | MHz | Mega-Hertz
h | hour | µA | Micro-Ampere
hPa | hecta Pascal | N | Newton
Hz | Hertz | Pa | Pascal
km | kilometer | s | second
kPa | Kilo Pascal | V | Volt
KB | Kilo Byte | Kg | Kilo gram

Table 1: Abbreviations and their Full Forms

# 4 Systems Overview

## 4.1 Mission Summary

The following tables lists all the Objectives of the INSPACe CANSAT Competition, 2024-2025.

Main Objectives

Design an “Innovative Mechanical Gyro-control” system that shall demonstrate the descent control of

the CANSAT

1. Weight and Cost Design: | The CanSat shall have a mass of 1000 +/- 50 grams, meet specific dimensional requirements and survive structural and environmental forces. Ensure the cost remains under 1,00,000 rs.
2. Dimensions: | CanSat shall fit in a cylinder of 0.15m diameter and 0.40m height and have tolerances to ensure deploy-ment from rocket fairing.
3. Gyroscope: | CanSat shall stabilize itself during the descent using the Mechanical Gyroscopes.
4. Structural Integrity: | CanSat structure shall be built to survive 15 Gs of launch acceleration & 30 Gs of shock. All electronics shall be enclosed and shielded from the environment. No electronics can be exposed except for sensors. There must be a structural enclosure.
5. Electronics and Telemetry: | The CanSat shall continuously sense and transmit a variety of sensory data from launch and stop this transmission upon landing.
6. Ground Station and Flight Software: | Develop a ground station that calibrates altitude, generates CSV files, and displays telemetry in real-time during descent. The software must also implement a ”Simulation mode”.

Bonus Objectives

1. Novel descent trajectory Control, Innovative materials.
2. Additional Innovative Sensors and Communication Systems.
3. Provision of video capture from separation till final touchdown.
4. Innovative recovery techniques viz. HAM radio/Advanced beacons.
5. Innovative Quality and reliability analysis methodologies.

## 4.2 CONOPS

Sr. No. | Event | Altitude | Description
1. | Separation from Rocket | 1000 m | The CanSat is ejected from the rocket.
2. | Drogue chute Deployment | 1000 m | The drogue parachute is deployed, descent rate 17 m/s.
3. | Descent by Drogue chute | 1000 - 500 m | Descent by drogue chute and Gyroscope mechanism stabal-izes the CANSAT.
4. | Main chute Deployment | 500 m | Main parachute deploys, descent rate reduces to 2m/s
5. | Descent and Data Collection | 500 – 100 m | The onboard systems actively gather and store data, and potentially transmit it to ground control.
6. | Landing leg deployment | 100 m | The landing legs are deployed, and the CanSat’s Active Gyro Control mechanism enters high power mode
7. | Landing and recovery | 0 m | CanSat lands safely and is recovered

## 4.3 System Level Requirements Compliance

Req. No. | Requirements | Compliance
1. | Total mass of the CANSAT shall be under 1000gm (+/- 50 gm). | Comply
2. | CANSAT shall fit in a cylindrical body of 0.15 m diameter x 0.40 m height. Tolerances are to be included to facilitate container deployment from the rocket fairing. | Comply
3. | Any sharp edges on the container body shall be avoided as it can cause interference during the CANSAT ejection from the rocket. | Comply
4. | Colour of the CANSAT body shall be fluorescent i.e., pink, red or orange, and shall embody the Indian flag. | Comply
5. | Rocket Airframe will not be allowed to be used as a part of any CANSAT operation. | Comply
6. | The CANSAT shall consist of necessary sensors to provide the following mandatory Real-time datasets: Position data, altitude, pressure, temperature, orientation data, power data & system status. | Comply
7. | Each data field shall be displayed in real-time on the ground station user interface/software. | Comply
8. | CANSAT shall also record the data and save it into an onboard SD card in case of telemetry connection loss. | Comply
9. | All electronics shall be enclosed and shielded from the environment. No electronics can be exposed except for sensors. There must be a structural enclosure. | Comply
10. | CANSAT structure shall be built to survive 15 Gs of launch acceleration & 30 Gs of shock. | Comply
11. | Electronic circuit boards must be hard mounted using proper mounts such as standoffs and screws. High-performance adhesives can also be used. | Comply
12. | Team number, email address and phone number must be placed on the structure in English, Hindi and the Regional language of the launch state to aid in recovery. | Comply
13. | An audio beacon shall be installed on CANSAT as a recovery assist. It may be powered after landing or operate continuously. The audio beacon must have a minimum sound pressure level of 92 dB, unobstructed. | Comply
14. | The CANSAT shall have an external power switch with an indicator light or sound for being turned on or off, in order to avoid the de-assembling of CANSATs on the launch pad. | Comply
15. | The CANSAT shall have a battery capacity to support up to 2 hours of wait in on the launch pad with additional time for flight operations. | Comply
16. | Spring contacts shall not be used for making electrical connections to batteries. | Comply

17. | The battery source may be alkaline, Ni-Cad, Ni-MH or Lithium ion. Lithium polymer batteries are not allowed. Lithium cells must be manufactured with a metal package similar to 18650 cells. | Comply
18. | An easily accessible battery compartment must be included allowing batteries to be installed or removed in less than a minute and not require total disassembly of the CANSAT. | Comply
19. | The CANSAT shall contain a total of 2 descent control mechanisms, to be used at different stages while descent. | Comply
20. | CANSAT shall immediately deploy the first parachute after ejection from the rocket. | Comply
21. | The first parachute shall be connected to the outer body of the CANSAT and no ejection mechanism shall be attached to it. | Comply
22. | The descent rate of the 1st parachute shall be 20 m/s +/- 5m/s. | Comply
23. | The second descent control mechanism shall open at an altitude of 500m (+/-10 m) to further decrease the descent rate of the CANSAT to 1 to 3m/s. | Comply
24. | The descent control system shall not use any hazardous chemical-based explosive or pyrotechnic devices. However, green propulsion is allowed if being used under the same weight constraint. | Comply
25. | CANSAT shall stabilize itself during the descent using the mechanical gyro mechanism. | Comply
26. | The CANSAT communications radio shall be the XBEE radio series 1/2/pro. | Comply
27. | The XBEE radios shall have their NETID/PANID set to the team number. | Comply
28. | The XBEE radio shall not use the broadcast mode. | Comply
29. | The XBEE radio can operate in any mode as long as it does not interfere with other XBEE radios. | Comply
30. | Each team shall develop and use their own ground station. All telemetry shall be displayed in real-time during launch and descent. All telemetry shall be displayed in engineering units (meters, meters per second, Celsius, etc.). Teams shall plot data in real-time during flight. | Comply

## 4.4 Changes/Modifications done from PDR round

Sub-System | Change | Rationale
Mechanical | Rod & Plate Interfacing: Larger diameter car-bon fiber rods instead of stacks. Landing Mechanism: Landing legs instead of crush core. Section Dividers: Modified plate geometry. Gyro: Split into two sections. Nichrome Wire: Added for deploying landing legs. | Better support, reduced mass, improved de-sign. More stable and reliable landing. More reliable design to hold outer shield of CanSat. Larger diameter, efficient use of space. Reliable and robust design.
Descent Control | Parachutes sizing changed Slight changes in deployment mechanism | For added reliability and robustness For easier and smoother parachute deploy-ment
CDH | Rod-type antenna replaced with a sticker-type antenna. RTC module replaced. Using 2 Raspberry Pis instead of 1. | Mass reduction, better suited for structure. Availability. Redundancy, extra CSI port for bonus camera.
EPS | Battery changed. | Weight reduction.
FSW | Sampling rate changed from 25Hz to 10Hz. Partially integrated two cameras in flight soft-ware. Backup processor added. Logic changes. | Reduces compute load. Bonus task undertaken. Fallback safety in case of reset. Increased precision.
GCS | GCS antenna changed. Interactive dashboard added. | Cost cutting while maintaining performance. Easy to observe incoming data.

## 4.5 Physical Layout & Dimensions

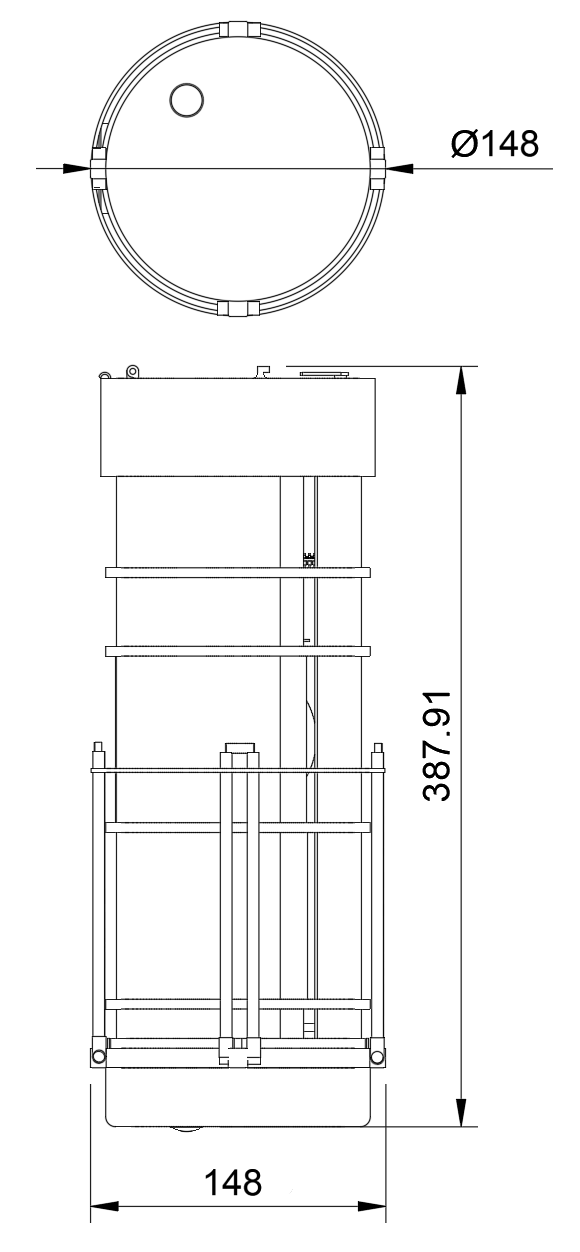
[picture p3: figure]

Figure 1: Physical Layout

Dimensions | Mission Requirements | CAD Models | Margins
Diameter | 0.15m | 0.148m | 0.002m
Height | 0.40m | 0.387m | 0.013m

### 4.6 Color Coding Scheme of CANSAT

Sr No | Parts/Location | Colour | Reasoning
1. | Outer Casing | Saffron, White, Green | Enhanced Visibility and Ease of track-ing during Descent and Recovery
2. | Electronics and Electricals | Fluorescent Green | Ease of Locating by Visual Inspection
3. | First Parachute | Fluorescent Pink | Mission Requirement and Ease of Tracking
4. | Second Parachute | Fluorescent Red | Mission Requirement and Ease of Tracking
5. | Gyroscope and Other Mechanical Components | Grey, White | Ease of Locating by Visual Inspection
6. | Lower Shell | Transparent | Required for Video Recording
7. | Structural Elements | Black | Ease of Locating by Visual Inspection

# 5 Mechanical Subsystem

### 5.1 Mechanical Subsystem Overview

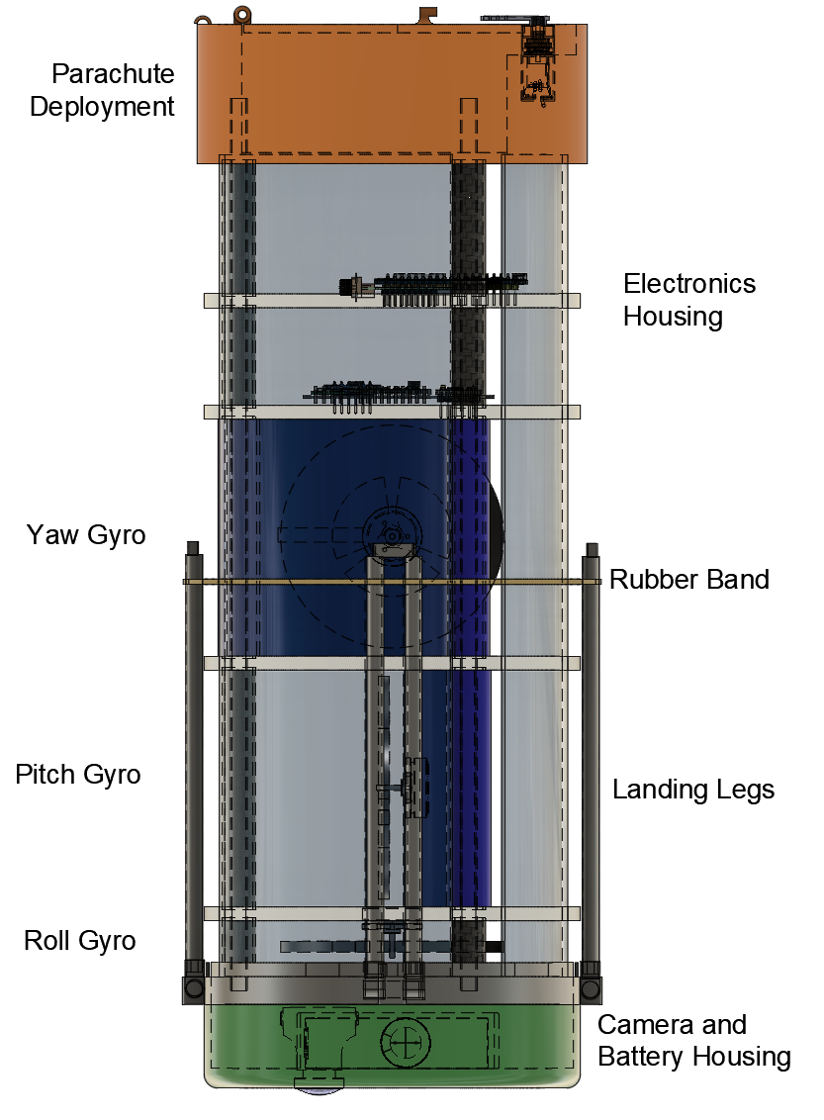
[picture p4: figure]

Figure 2: Cansat Structure

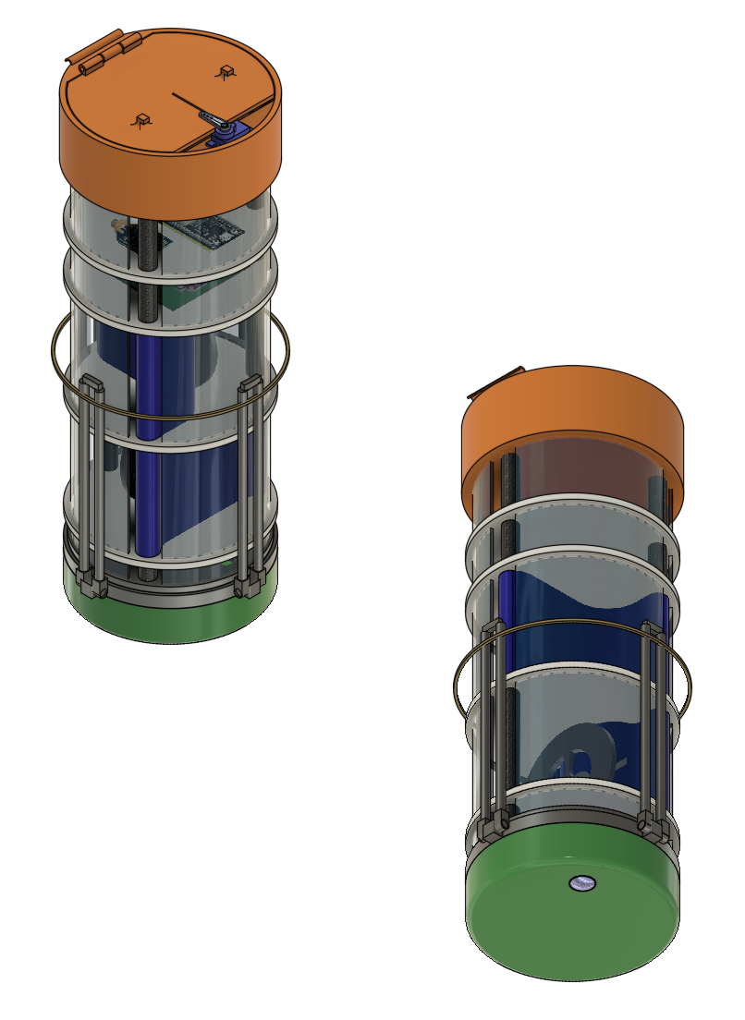
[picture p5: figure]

Figure 3: Isometric View of Cansat Structure

### 5.2 Materials Selection

Materials Selection

Component | Material | Pros | Cons | Rationale
Outer Covering | Plastic mesh | Lightweight | Bendable and might bend | To conserve weight, aid aerodynamic stability
Rods (Structural Support & Spacer) | Carbon Fiber | High Load bearing capacity | Relatively expen-sive | Needed for structural in-tegrity under load
Parachute | Nylon Rip-stop Fabric | Proven reliability | Bulkier when packed | Ensures controlled descent
Landing Legs | Carbon fiber | Easy to procure | Expensive, Brittle | absorbs shock during landing
Fasteners | Steel Screws | High strength | Adds to overall weight | Essential for secure con-nections

### 5.3 Changes Since PDR

- The previous stack design for the main structure proved to be very heavy. So, we moved to a simpler design that uses

carbon fibre rods as spacers.

- The chosen landing structure was a Crush Core, but upon further consideration we decided to use a Landing Leg system

that would be much more reliable.

- The plate design was changed from having protrusions to just have slits that the outer cover can slide into. This gives the

outer cover more stability.

### 5.4 CanSat Body

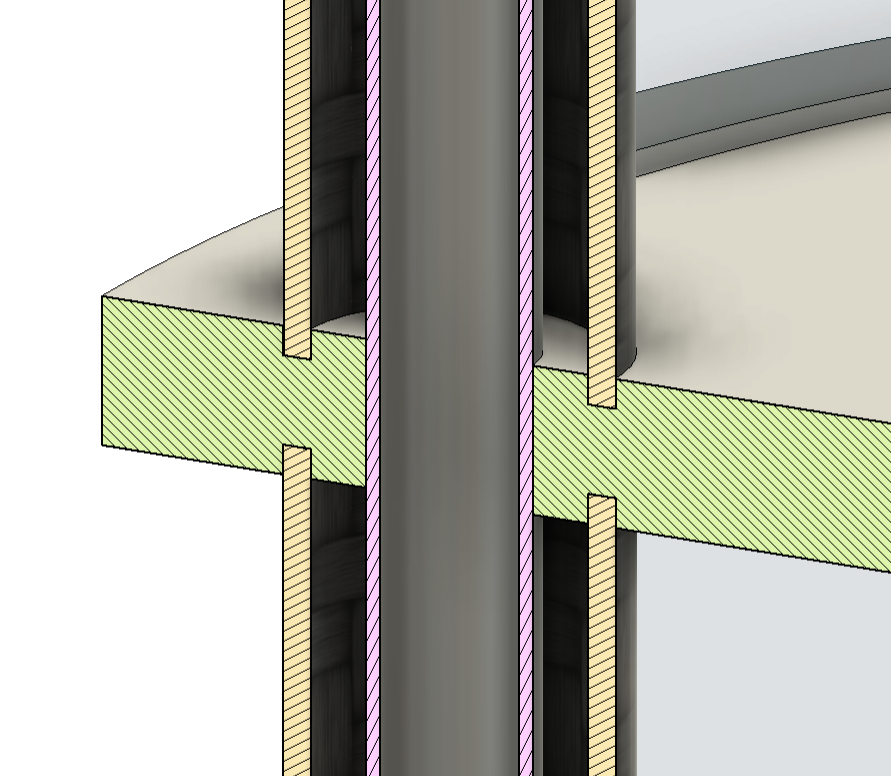
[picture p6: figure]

(a) Spacer Design for Plates | (b) Top View

Figure 4: Structure Details

The main structural integrity of the cansat is provided by three carbon fiber rods that go throughout it. There are plates made

to hold the components that have slots to add thicker carbon fiber rods. These add more structural integrity and also help to

keep the plates in place. The outer cover is made using plastic mesh that will be slotted in throughout the cansat.

### 5.5 Parachute Container

(a) Before Deployment | (b) After Deployment

Figure 5: Deployment Mechanism

The parachute container is held close by a servo motor. There is also a rubber band which tensions the lid to open. When the

servo swivels out of the way, the lid opens and the secondary parachute is deployed.

### 5.6 Landing Subsystem

The landing subsystem is responsible for ensuring that the cansat has a stable and controlled touchdown. As the terrain is

expected to be predominantly rocky and the launch will take place in a wide open area, our landing system must be able to cope

with those conditions.

Figure 6: Strut-Based Landing Gear

The strut-based landing gear system consists of foldable legs that remain

stowed during launch and the initial descent phase. These legs are secured

using nichrome wire, which is severed when the CanSat reaches an altitude

of 250 meters, triggering the deployment of the landing legs.

Key Features:

- The legs are tensioned downward using rubber bands, ensuring they

deploy in the correct orientation.

- Carbon fiber components, combined with the cushioning effect of the

rubber bands, help absorb impact forces.

- Compact storage allows better space utilization for sensors and cam-

eras.

(a) Landing Legs Undeployed | (b) Landing Legs Open

Figure 7: Landing Legs

Figure 8: Battery Compartment and Camera

### 5.7 Base Plate and Battery Compartment

The base plate features compartments designed to securely hold the battery cells. It also includes a cutout at the bottom to

accommodate the camera lens. Additionally, portions of the power circuitry are housed within this section. The main structural

rods will be firmly anchored to this base, ensuring stability and support.

### 5.8 Parachute Testing

We tested our parachute system using a mass simulator. The parachute has a diameter of 120 cm and a spill hole of 12 cm,

designed to ensure a controlled descent during CanSat deployment.

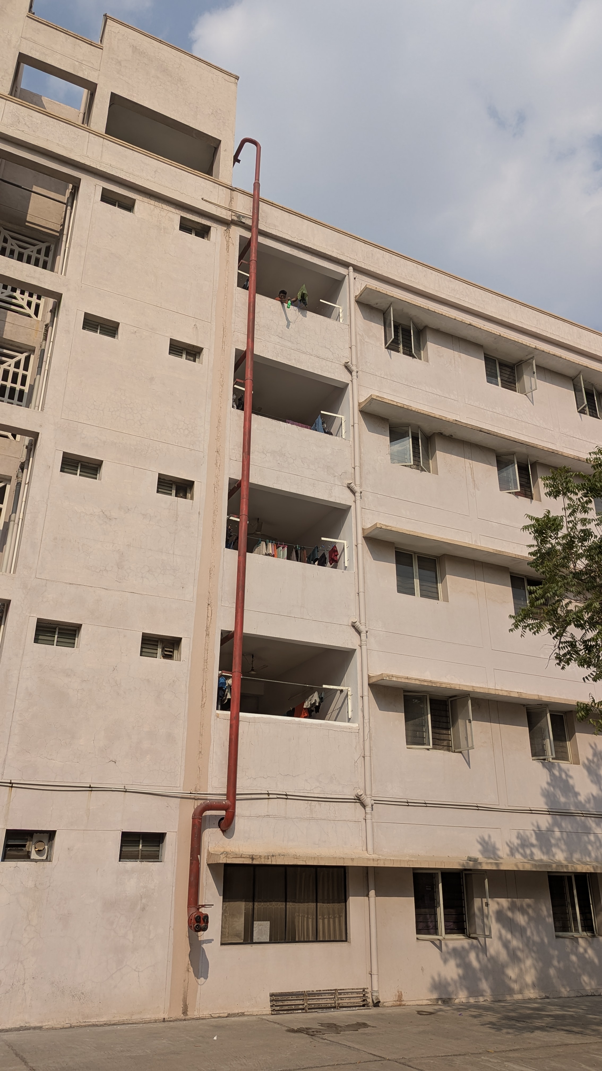
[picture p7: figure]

Figure 9: CanSat drop test

The drop test involved releasing the mass simulator from

a predetermined height and recording its positional data over

time. This data was used to determine the descent profile and

to extract the terminal velocity during the stabilized phase

of the fall. The recorded trajectory was later analyzed using

dedicated software, as shown in Figure ??.

### 5.8.1 Goal:

The aim of this analysis is to predict the theoretical terminal

velocity of the parachute system based on its design param-

eters and compare it with the observed descent rate during

the drop test. This comparison validates that the parachute

provides adequate deceleration for a safe landing.

### 5.8.2 Calculation:

The terminal velocity vt is determined from the equilibrium

between the gravitational force and the aerodynamic drag

force:

mg =

1
2

ρv²
t CDA,

where:

- m is the mass of the simulator ( 1.0 kg),
- g = 9.81 m/s²
is the acceleration due to gravity,
- ρ = 1.225 kg/m³
is the air density,
- CD = 1.5 is the drag coefficient (estimated for a hemi-

spherical parachute),

- A = π(0.6 m)² ≈ 1.13 m²
is the effective canopy area.

Rearranging for vt:

vt =

r
2mg
ρCDA

Substituting the values, we get:

vt ≈

r
2 × 1.0 × 9.81
1.225 × 1.5 × 1.13

≈

r
19.62
2.0779

≈

√
9.44 ≈ 3.07 m/s.

### 5.8.3 Drop and Analysis:

During the drop test, the descent velocity was derived by differentiating the y-coordinate data over time. The observed terminal

velocity, measured during the stable portion of the descent, ranged between approximately 5.4 and 6 m/s.

This observed range is slightly higher than predicted the theoretical prediction of 3.07 m/s.

We are currently making and will test a parachute with a slightly larger diameter.

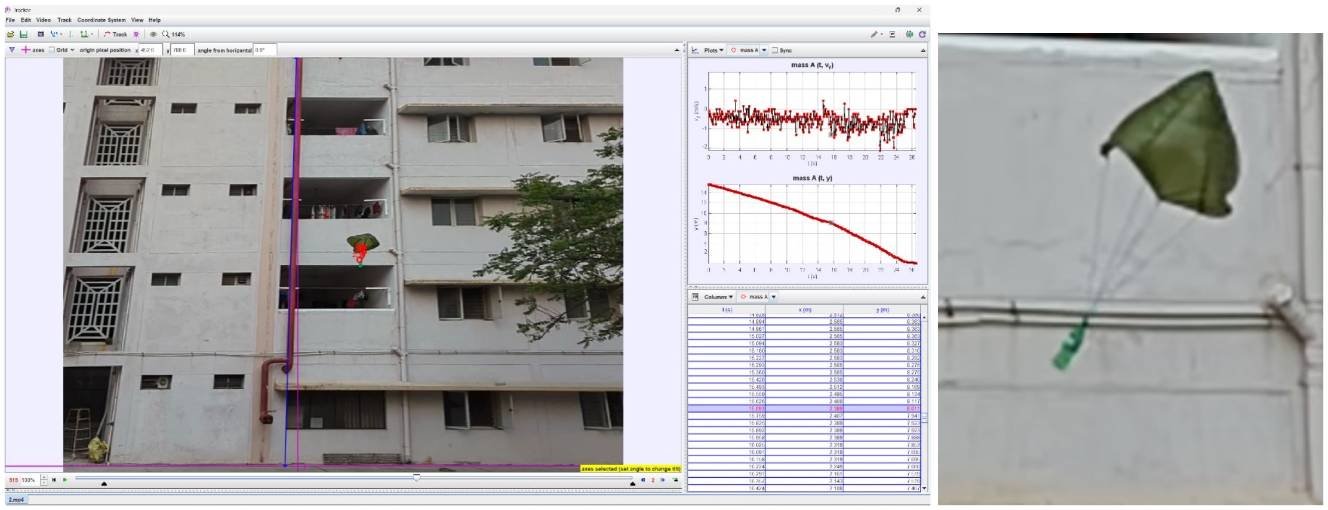
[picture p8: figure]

### 5.8.4 Conclusion:

The theoretical analysis predicts a terminal velocity of approximately 3.07 m/s, which lower than observed values from the drop

test 5 m/s. This is probably due to the parachute rigging and parachute settling into a suboptimal configuration (conical rather

than hemispherical).We will explore different rigging mechanism and attach cords along the spill hole as well to improve stability.

We will also test a swivel to reduce rotation of can sat due to the parachute.

# 6 Communications & Data Handling

# Subsystem

## 6.1 CDH Subsystem Overview

To ensure robust and reliable data transmission from the CanSat to the Ground Station, we have integrated two independent

communication systems. The primary system utilizes an XBee Pro S2C radio module, which provides real-time telemetry

transmission with a long-range RF link. As a backup, we have implemented a GSM-based communication system using the

SIM808 module, which enables data transmission over cellular networks. This redundancy ensures continuous data flow even in

the event of primary system failure, enhancing the overall reliability of the mission.

### 6.1.1 Changes since PDR

- ESP-WROOM-32 selected as payload computer due to high availability, ease of integration, and better integration with

available sensors.

- XBEE ProS2C selected as the default payload radio.
- GSM808 added as a secondary method to send telemetry data.
- Added sticker antenna for better integration
- Added coin cell powered RTC for better accuracy

### 6.2 Payload Processor Selection

- Name: ESP-WROOM-32E
- CPU: Xensa dual-core 32-bit LX6
- Processor Speed(MHz): 80 - 240
- Memory: 448 KB ROM, 520 KB SRAM and 16KB SRAM in RTC
- Data Interfaces: GPIO (x38), UART (x2), SPI (x2), I2C (x2), PWM (x23), Analog (x16)
- Input Voltage: 3.6 V
- Operating Temperature(C): -40 to 85

- Reason for Selection:

– Powerful Dual Core Processor

– High Clock Speed

– Sufficient pins for Sensors planned to use

– Ease in Trouble Shooting for errors

– Existence of plentiful guides on the Internet

– Can be stripped down to have a chipset for PCB

– Ease of coding and availability of Libraries

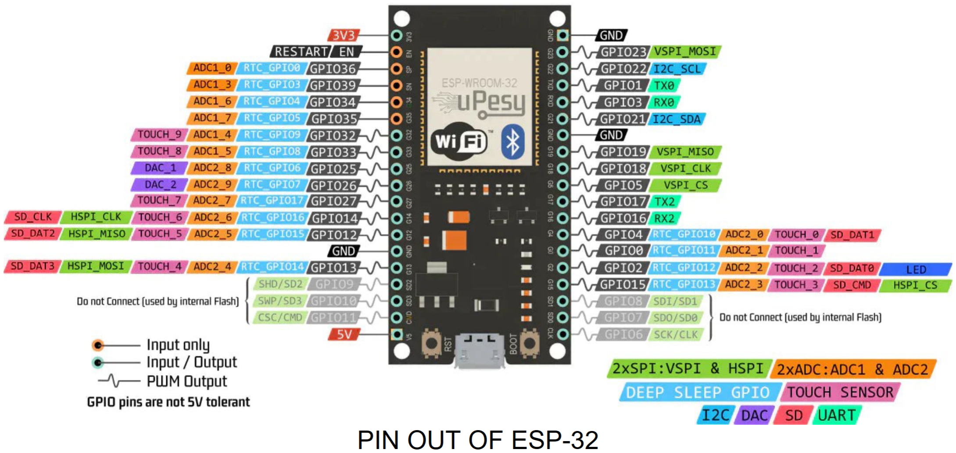
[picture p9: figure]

Figure 10: Payload Computer

### 6.3 Payload Memory Selection

- Name: SanDisk Ultra microSD UHS-I Card
- Storage Capacity: 32 GB
- Data Read Speed: 120 MB/s
- Speed Class: 10
- Reason for Selection:

– Faster data read and write speeds

– Already available

Figure 11: Payload Memory

### 6.4 Primary Radio Selection

- Name: XBee Pro S2C
- Operating Frequency: 2.4 GHz
- Transit Current: 120 mA @ 3.3 VDC
- Receive Current: 31 mA @ 3.3 VDC
- Transmit Power: 63 mW (+18 dBm)
- RF LOS Range: 3.2km
- Setup:

– All generated packets are primarily sent through the XBee communication system at a rate of 1 Hz.

– Data is received at the Ground Station via another XBee connected to an ESP32, which is further connected to a

laptop.

– We are exploring the possibility of bypassing the extra ESP32 at the Ground Station, but this current setup has been

tested and proven reliable.

Figure 12: XBEE Pro S2C

### 6.5 Secondary Communication (GSM Module)

- Name: GSM SIM808
- Supports Quad-band 850/900/1800/1900MHz, compatible with all 2G networks all around the world.
- Inner MT3337 GPS receiver, -165dBm precision, control on a same serial port.
- Sending and receiving SMS.
- Sending and receiving GPRS data (TCP/IP, HTTP vb).
- UART communication with automatic baud rate settings.
- Comply with GSM phase 2/2 +

Class 4 (2 W @ 850 / 900MHz)

Class 1 (1 W @ 1800 / 1900MHz)

- Support low power consumption mode: 100mA @ 7V-GSM mode
- Support AT command control (3GPP TS 27.007,27.005 and SIMCOM enhanced AT Commands)
- Working environment: -40 ℃ 85 ℃

– Reports are sent every 10 seconds (0.1 Hz) to a remote server.

– The lower transmission rate is due to the peak power consumption of 2A that occurs each time a packet burst is sent.

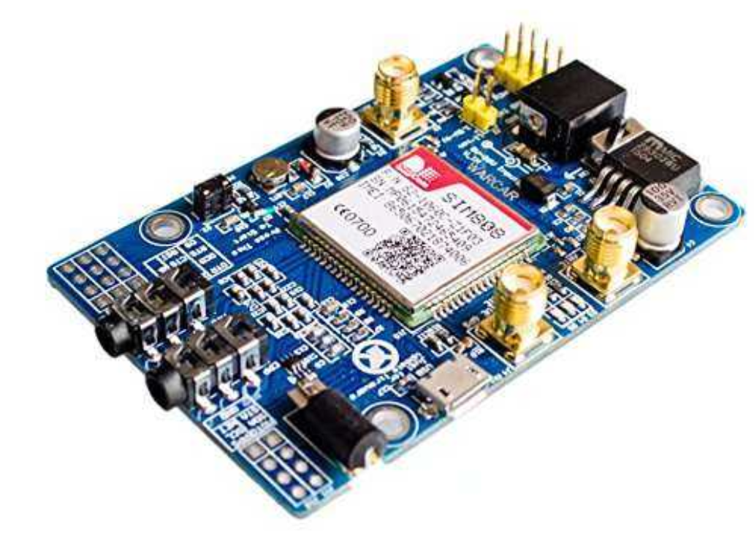
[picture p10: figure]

Figure 13: GSM Sim 808 Module

### 6.6 Payload Real-Time Clock

- Selected RTC: DS3231

– Uses button/coin cell for power supply, thus remaining independent from power fluctuations and processor resets

– High accuracy

- Module Specifications:

– Max Current: 200 µA

– Accuracy: ±2 ppm from 0 to 40°C, ±3.5 ppm from -40 to +85°C

– Operating Temperature: -40 to +85°C

– Output Protocol: I²C

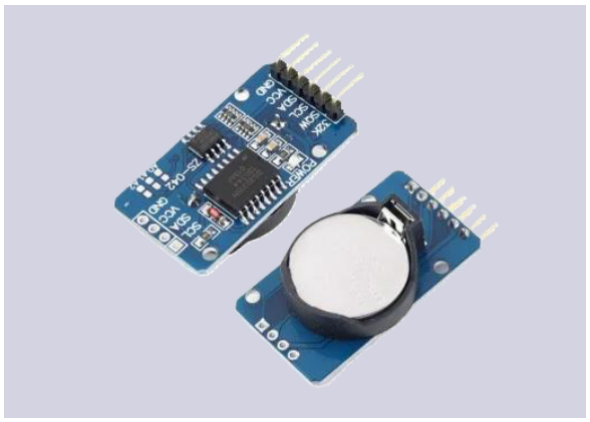
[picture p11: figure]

Figure 14: Payload RTC

### 6.7 Payload Antenna Selection

- Selected Antenna: Lambdoid Sticker Antenna

– Less mass

– Low cost

– Has a flexible PCB allowing to wrap and stick the antenna around the exterior of the CanSat

- Antenna Specifications:

– Gain: 3 dBi

– Operating Band: 2.4 – 2.5 GHz

– HPBW: 360°

– VPBW: 30°

– Type: Omni-Directional

– Mass: 3 g

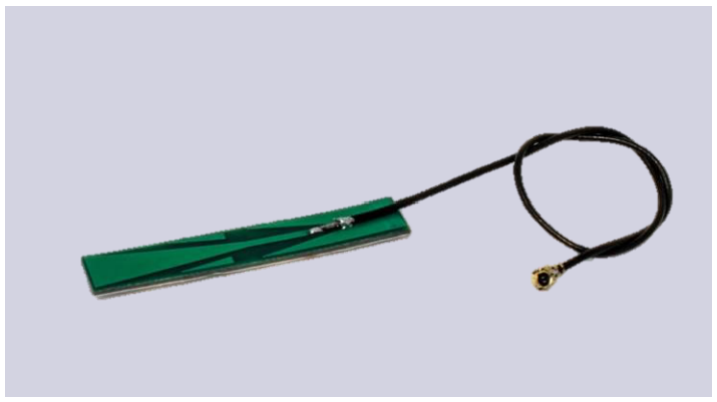
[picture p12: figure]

Figure 15: Payload Antenna

## 6.8 Data Handling

1. XBee Data Storage
- Data sent via XBee is stored directly on a laptop at the Ground Station.
- Both raw and processed packets are retained for analysis.
2. GSM 2G Data Storage
- Data sent via GSM is stored on a remote cloud server.
- Both raw and processed packets are retained for redundancy and further analysis.
3. Visualization, Logging and Terminal
- A visualization software will run on both the laptop and the cloud server.
- Terminals at both locations will provide real-time monitoring.
- All transmitted communication will be logged for post-mission review.

### 6.9 Onboard Data Storage

- Flight Data Storage

– The flight controller is connected to a microSD module.

– Each report is stored as a record in a CSV file.

- Camera Storage

– Footage from the camera is stored on the CanSat using a dedicated microSD card in a closed-loop system.

– The ESP32 (flight controller) does not interact directly with the camera except for controlling a relay to power the

system.

– The camera and storage system are integrated and operate at fixed intervals once powered.

### 6.10 Payload Telemetry Format

### 6.10.1 Transmission Details

- Telemetry is transmitted at a rate of 1 Hz.
- The format matches competition guide specifications.

### 6.10.2 Telemetry Format

The telemetry format follows:

<TEAM_ID>,<MISSION_TIME>,<PACKET_COUNT>,<MODE>,<STATE>,<ALTITUDE>,<AIR_SPEED>,<HS_DEPLOYED>,<PC_DEPLOYED>,

<TEMPERATURE>,<PRESSURE>,<VOLTAGE>,<GPS_TIME>,<GPS_ALTITUDE>,<GPS_LATITUDE>,<GPS_LONGITUDE>,<GPS_SATS>,

<TILT_X>,<TILT_Y>,<ROT_Z>,<CMD_ECHO>

### 6.11 TTLC Fit Check and Interference Analysis

### 6.11.1 TTLC Fit Check

- Component Placement Verification

– XBee Pro S2C and antenna placement has been optimized for omnidirectional transmission with minimum blockage

from other components.

– SIM808 GSM module is positioned with adequate separation from other electronics to minimize EMI.

– Antenna elements secured with vibration-resistant mounts to maintain orientation during flight.

- Internal Wire Routing

– Signal wires for RF components follow specific paths to minimize crosstalk.

– Power lines to the SIM808 are separated from sensitive data lines to reduce noise coupling.

– Coaxial cable connections to antennas include strain relief to prevent disconnection during deployment events.

### 6.11.2 RF Jamming and EMI Analysis

- Internal RF Interference Sources

– Microcontroller clock (ESP32) - Measured emissions at operational frequency: -55 dBm at 20 cm

– Camera module - Shielded with aluminum foil tape to reduce emissions

- Interference Mitigation Techniques

– Have to implemented frequency filtering on both transmit and receive paths

– Utilized separate ground planes for digital and RF circuitry

– Have to conduct RF isolation testing in operational configuration

- Test Results

– No measurable degradation in XBee signal quality with all systems powered. Further testing ongoing.

– Packet Loss Test ongoing.

### 6.12 RF Link Margin and Antenna Characterization

### 6.12.1 XBee Pro S2C Link Budget Analysis

- Transmitter Characteristics

– Output Power: 18 dBm (configured to maximum allowed power)

– Operating Frequency: 2.4 GHz ISM band

– Data Rate: 250 kbps

– Antenna Gain: 3 dBi (sticker antenna)

- Path Loss Calculation

– Maximum Required Range: 1 km

– Path Loss Model: Free space + terrain factor (2.3)

– Calculated Path Loss at 1 km: -100 dB

– Atmospheric Absorption: -0.3 dB (average humidity conditions)

- Receiver Characteristics

– Ground Station Antenna Gain: 12 dBi (3AN High Gain WiFi Router Antenna)

– Receiver Sensitivity: -102 dBm at 250 kbps

– Noise Floor: -110 dBm (measured)

– Required SNR: 8 dB

- Link Margin Calculation

– Received Signal Strength at 1 km: -69 dBm

– Margin above Sensitivity: 33 dB

– Worst-case Margin (accounting for pointing errors): 25.5 dB

### 6.12.2 SIM808 GSM Antenna Performance

- Antenna Specifications

– Type: PCB trace antenna with matching network

– VSWR: 1.8:1 at GSM 900 MHz band

– VSWR: 2.1:1 at GSM 1800 MHz band

– Efficiency: 65% (measured)

- Network Connectivity Testing

– Average Signal Strength (RSSI): -75 dBm in field conditions

– Packet Delivery Rate: 97.8% during field testing

– Reconnection Time after Signal Loss: 12 seconds (average)

### 6.12.3 Antenna Radiation Pattern Measurements

- XBee Pro S2C Antenna

– Azimuthal Pattern: Near-omnidirectional with ±2.5 dB variation

– Elevation Pattern: 70° -3 dB beamwidth

– Null Depth at 90° elevation: -16 dB

– Polarization: Vertical

- Ground Station Antenna

– Forward Gain: 12 dBi

– -3 dB Beamwidth: Narrow, optimized for long-distance communication

– Side Lobe Suppression: -12 dB

### 6.13 Failure Modes and Effects Analysis (FMEA)

### 6.13.1 Communication System Failure Modes

Failure Mode | Potential Causes | Effects | Mitigation | Criticality
XBee Link Loss | Antenna damage, power failure, software crash | Primary telemetry data loss, inability to receive commands | Redundant GSM link, watchdog timer for software reset, onboard data logging | High
GSM Connec-tion Failure | Network coverage gaps, SIM card issues, power spike | Loss of backup telemetry channel | Local data storage, power filter-ing circuits, network provider re-dundancy where available | Medium
Ground Station XBee Failure | Hardware failure, software crash, USB connection issues | Inability to receive real-time telemetry | Backup ground station equip-ment, software logging to detect issues early | High
Command Rejection | Packet corruption, incorrect format | Mission parameters cannot be updated | Command verification protocol, error detection, automatic retry mechanism | Medium
Onboard SD Card Failure | Write errors, card ejection during vi-bration | Loss of backup mis-sion data | Redundant storage systems, se-cure card mounting, pre-flight verification tests | Medium
RF Signal At-tenuation | Terrain obscura-tion, atmospheric conditions, im-proper orientation | Reduced range, in-termittent communi-cation | Higher gain ground antennas, signal strength monitoring, adaptive data rates | Medium
Power Bus Brownout | Momentary high current draw, bat-tery degradation | Communication sys-tem reset, loss of in-flight calibration | Power filtering, dedicated com-munication system power rail, brownout detection | High
Camera System Failure | Storage full, power interruption | Loss of visual mis-sion data | Separate power circuit, opti-mized storage usage, pre-flight capacity verification | Low

### 6.13.2 Recovery Procedures

- XBee Link Failure Recovery

– Automatic power cycling of XBee module after 30 seconds of no acknowledgment

– Store-and-forward capability for missed telemetry packets upon link re-establishment

– Automatic parameter reconfiguration upon restart

- GSM Reconnection Protocol

– Progressive retry timing (5s, 15s, 30s) to avoid power drain during extended outages

– Cached data transmission upon reconnection with priority flags

– Network provider selection logic based on signal strength

- Ground System Redundancy

– Backup laptop with duplicate software configuration

– Alternate XBee module pre-configured for quick swap

– Network-based data sharing to secondary monitoring stations

- Data Recovery Procedures

– Post-flight data extraction protocol from onboard storage

– Packet reconstruction algorithms for partial transmissions

– Timestamping mechanism to reconcile data from multiple sources

### 6.14 Future Improvements

- Optimize GSM transmission rate while managing power consumption.
- Implement error-checking and data redundancy mechanisms for XBee communication.
- Upgrade the photo storage system to allow higher quality image captures.
- Implement adaptive data rates based on link quality measurements.
- Add forward error correction for critical telemetry parameters.
- Develop ML-based signal prediction for better ground antenna pointing.

### 6.15 CDH and Radio Communications Subsystem Test Status

TEST | TEST DESCRIPTION | REQUIREMENT TO PASS | STATUS
GCS Battery Test | Turn on CanSat for transmit data for 2 hours. | The CanSat is still opera-tional after 2 hours of use. | PASS
Data Recovery Test (SD Card) | Write the data (altitude, packet count, states, coordinates etc.) to the SD Card. | The data written is present in the SD Card. | PASS
XBEE Setup Test (XBEE-Pro S2C) | Open XCTU application and connect XBEEs to the computer. Inspect XBEE radios for the operating frequency, PANID and transmission protocol through XCTU. | XBEEs are set up accord-ing to mission guide re-quirements. | PASS
SIM808 | Check if SIM808 is registered to network and is sending data to the GCS server through 2G | SIM808 is set up and send-ing data to GCS server. | ONGOING
Radio Communica-tion Test (Antenna) | Send CX, ON command. Walk 1km from the GCS while in line of sight and trans-mitting telemetry at 1Hz. Monitor incom-ing flight state on GCS and use GS to send commands to payload and observe changes. | The XBEEs remain con-nected with no packet loss. XBEE on CanSat receives all sent commands. | ONGOING
Camera Test | Turn Cansat On. Check if video gets stored in SD card. | The camera is recording and saving data to the SD Card | ONGOING
RF Isolation Test | Operate all systems simultaneously and measure signal quality metrics | No degradation in SNR when all systems active | ONGOING
Link Margin Verifi-cation | Field test with CanSat at 1km distance | Received signal > -90 dBm, packet error rate < 1% | ONGOING
EMI/EMC Testing | Measure emissions from CanSat in ane-choic chamber | Emissions below competi-tion requirements | NOT TESTED
Command Verifica-tion | Send full suite of commands from GS to CanSat | All commands properly executed and acknowl-edged | PASS

# 7 Sensor Subsystem

### 7.1 Sensor Subsystem Overview

This section details the sensor subsystem of our CanSat project. It covers the selection process, testing methodologies, and

integration strategies for the chosen sensors. The sensor suite is designed to gather critical environmental and flight data to meet

mission objectives.

### 7.2 Mission Objectives Addressed by the Sensor Subsystem

- Collect mandatory real-time datasets (Position, Altitude, Pressure, Temperature, Orientation, Power Data, System Status).
- Potentially collect data for bonus objectives (Air Quality, etc.).

### 7.3 Selection Criteria

The following criteria guided our sensor selection process:

- Low Power Consumption
- Small Size
- Availability
- Documentation
- Shock and Thermally Tolerant
- Fast Start Times
- Accuracy and Resolution

### 7.4 Core Sensors

S. No | Component | Purpose
1 | BMP390 | Pressure
2 | AHT21B | Temperature
3 | ADS1115 | Voltage
4 | MS 4525DO | Air Speed
5 | MPU9250 | Tilt and Rotation
6 | NEO-M8N | GPS Position
7 | BME680 | Redundancy
8 | M135 | Air quality (NOX)
9 | Prana Pas 01 outdoor | Air Quality
10 | MQ131 | Air quality (Ozone)
11 | DS3231 | Real time clock

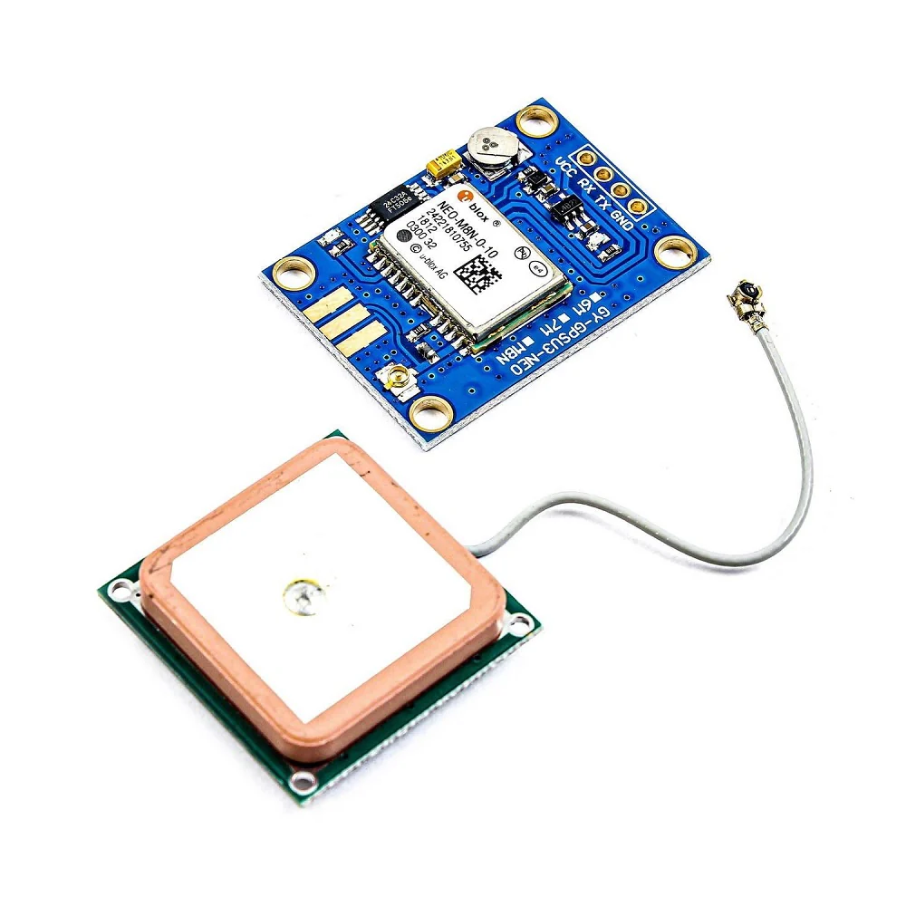
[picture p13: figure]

Figure 16: NEO-M8N

### 7.4.1 GPS - NEO-M8N

Based on our initial selection, we are using the NEO-M8N module. Further testing and verification details

follow:

Reasons for Selection | NaViC support, Good documentation, Compatibility with ESP32, Availability of breakout boards, Low power consumption, Multipath + external antenna support
Key Specs (Datasheet Values) | • Horizontal Position Accuracy: < 1.8 m CEP • Velocity Accuracy: < 0.1 m s⁻¹ • Power Consumption: – Acquisition: 99 mA @ 3.3 V – Tracking: 95 mA @ 3.3 V • Weight: 8.2 g • Update Rate: Up to 10 Hz

Testing Performed:

S. No | Component | Purpose
1 | Accuracy Tests: | We conducted static and dynamic accuracy tests to evaluate the GPS module’s performance. For the static test, the module was placed in a fixed location with clear sky visibility for 24 h. The recorded latitude and longitude values were compared to the known location. For dynamic testing, the module was tested in various conditions, such as on a car and also by walking with the module. The data was compared to the readings of a mobile phone GPS sensor.
2 | Start-Up Time Mea-surements: | Cold, warm, and hot start times were measured by powering the module on under different conditions. Cold start was measured after the module had been powered off for 24 h. Warm start was measured after the module had been powered off for 30 min. Hot start was measured after the module had been running less than 2 h.
3 | Power Consumption Measurements: | The current draw was measured using a multimeter in series with the power supply. Readings were taken during acquisition and tracking modes.

Testing Results:

Parameter | Value
Horizontal Accuracy (Static) | 2.5 m CEP (Average over 24 h)
Horizontal Accuracy (Dynamic) | 3 m CEP (Average)
Velocity Accuracy | 0.08 m s⁻¹
Power Consumption (Acquisition) | 97 mA
Power Consumption (Tracking) | 93 mA
Cold Start Time | 32 s
Warm Start Time | 2 s
Hot Start Time | 1 s

Integration Details: The GPS module is connected to the ESP32 via UART. (See Figure ??). It is mounted on the top

plate of the CanSat, away from potential sources of interference.

Code Snippet:

# include < SoftwareSerial .h >

# include < TinyGPS ++. h >

SoftwareSerial ss (4 , 3) ; // RX , TX

TinyGPSPlus gps ;

void setup () {

Serial . begin (9600) ;

ss . begin (9600) ;

}

void loop () {

while ( ss . available () > 0) {

gps . encode ( ss . read () );

if ( gps . location . isUpdated () ) {

Serial . print (" Lat :␣") ; Serial . print ( gps . location . lat () , 6) ;

Serial . print ("␣ Lng :␣"); Serial . print ( gps . location . lng () , 6) ;

Serial . print ("␣ Alt :␣"); Serial . print ( gps . altitude . meters () );

Serial . print ("␣ Time :␣"); Serial . print ( gps . time . hour () ); Serial . print (":");

Serial . print ( gps . time . minute () ) ; Serial . print (":"); Serial . println ( gps . time . second () );

}

}

}

Error Analysis: Potential sources of error include multipath interference, atmospheric conditions, and satellite geometry.

To mitigate these errors, we are using an external antenna and implementing a Kalman filter to smooth the GPS data.

Calibration Procedures: No specific calibration is performed. We are using the altitude provided from the ground level

as our altitude of 0.

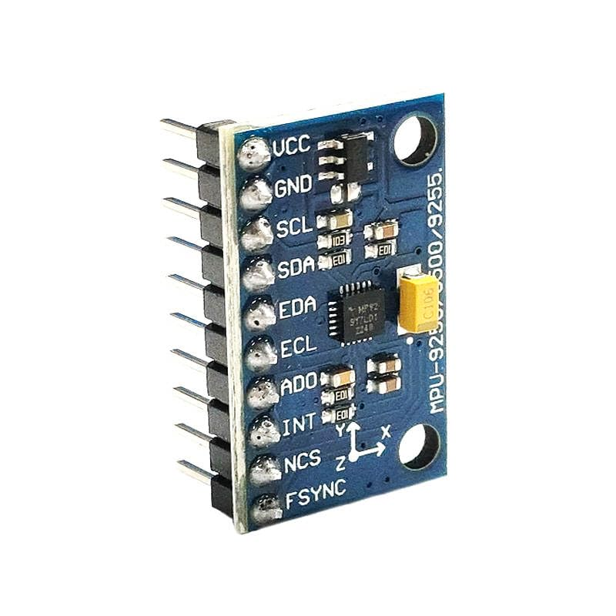
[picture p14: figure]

Figure 17: MPU 9250

### 7.4.2 IMU - MPU9250

Based on our initial selection, we are using the MPU9250 IMU module. Further testing and verification details

follow:

Reasons for Selection | Need a very fast sensor readout due to the gyro control system, good documentation, Compatibility with ESP32, Availability of breakout boards, low power
Key Specs (Datasheet Values) | • Interface: I2C, Max. bit rate up to 400 kbit s⁻¹ • Sampling Rate: Up to 4 kHz • Power requirements: 3.3 V • Current Draw: 3.9 mA (typical) • Weight: 10 g

Testing Performed:

S. No | Test | Procedure
1 | Noise Measurements: | We characterized the noise floor of the gyroscope and ac-celerometer by collecting data for 10 min while the sensor was stationary.
2 | Bias Stability: | We measured the bias drift over time by recording the gy-roscope output for 1 h while the sensor was stationary and at a constant temperature.

Testing Results:

Parameter | Value
Gyroscope Noise (X-axis) | 0.01 °/s/√
| Hz
Gyroscope Noise (Y-axis) | 0.009 °/s/√
| Hz
Gyroscope Noise (Z-axis) | 0.011 °/s/√
| Hz
Accelerometer Noise (X-axis) | 100 µg/√
| Hz
Accelerometer Noise (Y-axis) | 98 µg/√
| Hz
Accelerometer Noise (Z-axis) | 102 µg/√
| Hz
Gyroscope Bias Stability (X-axis) | 10 °/hr
Gyroscope Bias Stability (Y-axis) | 9 °/hr
Gyroscope Bias Stability (Z-axis) | 11 °/hr

Table 5: MPU9250 Testing Results

Gyro Calibration: We are using a static calibration procedure to compensate for gyroscope bias. The sensor is held

stationary for 5 min, and the average gyroscope output is calculated. This average value is then subtracted from subsequent

readings to remove the bias.

Sensor Fusion: We are implementing a complementary filter to fuse accelerometer and gyroscope data. This filter combines

the high-frequency accuracy of the gyroscope with the low-frequency stability of the accelerometer to provide a more accurate

and stable orientation estimate.

Integration Details: The IMU is connected to the ESP32 via I2C. (See Figure ??). It is mounted on the central PCB.

Code Snippet:

1 # include < MPU9250_asukiaaa .h >

2

MPU9250_asukiaaa mySensor ;

float aX , aY , aZ ;

void setup () {

Serial . begin (115200) ;

mySensor . beginAccel () ;

}

void loop () {

mySensor . accelUpdate () ;

aX = mySensor . accelX () ;

aY = mySensor . accelY () ;

aZ = mySensor . accelZ () ;

Serial . println ("X:␣" + String ( aX ) + ",␣Y:␣" + String ( aY ) + ",␣Z:␣" + String ( aZ ));

delay (500) ;

}

Error Analysis: Potential sources of error include gyroscope bias drift, accelerometer noise, and magnetic interference.

To mitigate these errors, we are using calibration procedures, sensor fusion algorithms, and shielding the sensor from magnetic

fields.

Figure 18: BMP390

### 7.4.3 Barometric Sensor - BMP390

Based on our initial selection, we are using the BMP390 barometric pressure sensor. Further testing and

verification details follow:

Reasons for Selection | Enough accuracy for our requirements, small size, and low power consumption.
Key Specs (Datasheet Values) | • Accuracy: ± 0.08 hPa absolute accuracy • Pressure Range: 300 hPa to 1100 hPa • Resolution: 0.005 hPa • Temperature Accuracy: 0.5 ◦C • Power Consumption: 3.2 µA at 1 Hz sampling rate

Testing Performed:

S. No | Test | Description
1 | Accuracy vs. Calibrated Reference: | Compared the BMP390 readings to a NIST-calibrated digital barometer (Fluke 700G) across a range of pressures relevant to the CanSat’s ex-pected altitude profile.
3 | Temperature Dependence: | Characterized the pressure readings at different temperatures (using a temperature-controlled chamber) to quantify and compensate for any temperature-related drift.
4 | Long-Term Stability: | Recorded pressure readings at a constant pressure and temperature over 24 hours to assess the sensor’s stability and identify any long-term drift.
5 | Power Consumption: | Measure the values during the active collection periods.

Testing Results:

Parameter | Value
Pressure Accuracy | ±0.5 hPa (after calibration)
Resolution | 0.03 hPa (as specified)
Temperature Dependence | ±0.5 Pa/K (compensated in software)
Long-Term Drift | ±0.2 hPa/year
Power Consumption (at 1 Hz) | 3.2 µA

Table 6: BMP390 Testing Results

Integration Details:

The BMP390 communicates with the ESP32 microcontroller using the I2C protocol. The I2C address is 0x77. The sensor is

mounted inside the CanSat structure on a dedicated PCB, and we have been careful to avoid direct airflow onto the sensor to

minimize wind noise (Figure 19).

Figure 19: BMP390 Mounting Detail

Code Snippet:

1 | # include < Wire .h >
2 | # include < Adafruit_BMP3XX .h >

# define SEALEVELPRESSURE_HPA 1013.25

Adafruit_BMP3XX bmp ;

void setup () {

Serial . begin (57600) ;

while (! Serial );

if (! bmp . begin_I2C () ) {

Serial . println (" BMP3 ␣ sensor ␣ not ␣ found !") ;

while (1) ;

}

bmp . setTemperatureOversampling ( BMP3_OVERSAMPLING_8X ) ;

bmp . setPressureOversampling ( BMP3_OVERSAMPLING_4X );

bmp . setIIRFilterCoeff ( BMP3_IIR_FILTER_COEFF_3 );

}

void loop () {

if ( bmp . performReading () ) {

Serial . print (" Temp :␣"); Serial . print ( bmp . temperature ) ;

Serial . println ("␣$^ o$C ");

Serial . print (" Pressure :␣") ;

Serial . print ( bmp . pressure / 100.0) ;

Serial . println ("␣ hPa");

Serial . print (" Altitude :␣") ;

Serial . print ( bmp . readAltitude ( SEALEVELPRESSURE_HPA )); Serial . println ("␣m\n") ;

}

delay (2000) ;

}

Error Analysis:

Potential error sources include temperature drift, calibration errors, and environmental factors (e.g., rapid pressure changes

due to wind). We will implement a temperature compensation algorithm (based on our temperature dependence testing) and

a moving average filter to smooth the pressure readings. In the event of sudden pressure changes, multiple readings over the

period can be collected and take the appropriate action.

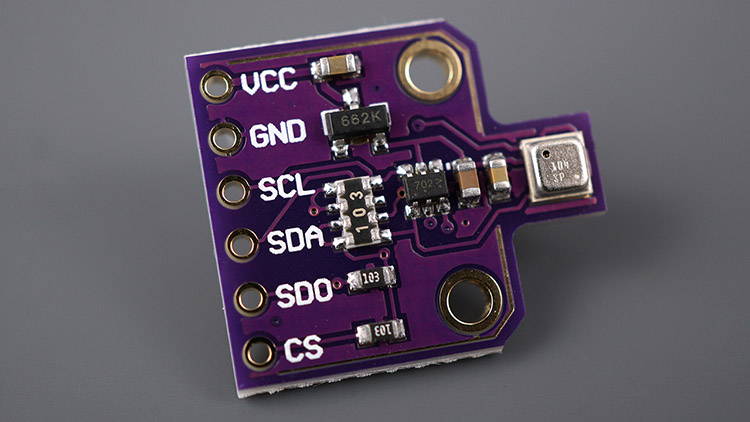
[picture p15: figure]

Figure 20: BME680

### 7.4.4 BME680 Environmental Sensor

Based on our initial selection, we are using the BME680 environmental sensor. Further testing and verification

details follow:

Reasons for Selection | Ability to measure pressure, temperature, humidity, and VOCs, all in a single compact sensor. I2C communication, and availability.
Key Specs (Datasheet Values) | • Pressure Range: 300 hPa to 1100 hPa • Pressure Accuracy: 0.6 hPa • Temperature Range: −40 ◦C to 85 ◦C • Temperature Accuracy: 0.5 ◦C • Humidity Range: 0 % to 100 % RH • Humidity Accuracy: 3 % RH • VOC Gas Sensor: Yes, measures VOC concentration

Testing Performed:

S. No | Test | Description
1 | Accuracy Tests: | All sensing features are validated against calibrated standards.
2 | Repeatability Tests: | Repeated measurements under constant environment.
3 | Long Term Stability: | Data collection process checked for long term stability.
4 | Power Consumption Tests: | Check the consumption and ensure it meets power guidelines.

Testing Results:

Parameter | Value
Pressure Accuracy | ±0.6 hPa
Temperature Accuracy | ±0.5 °C
Humidity Accuracy | ±3 % RH
Gas Sensor VOC Accuracy | ±10 %

Table 7: BME680 Testing Results

Integration Details:

The BME680 connects to the ESP32 using the I2C bus and is placed in a place where it is easy for air to reach.

Code Snippet:

1 | # include < Wire .h >
2 | # include < Adafruit_Sensor .h >
3 | # include " Adafruit_BME680 .h"

4

5 Adafruit_BME680 bme (& Wire ); // I2C

6

7 | void setup () {
8 | Serial . begin (9600) ;
9 | if (! bme . begin () ) {
10 | Serial . println (" Sensor ␣ not ␣ found !") ;
11 | while (1) ;
12 | }
13 | bme . setTemperatureOversampling ( BME680_OS_8X );
14 | bme . setHumidityOversampling ( BME680_OS_2X );
15 | bme . setPressureOversampling ( BME680_OS_4X );
16 | bme . setGasHeater (320 , 150) ;

17 }

18

19 | void loop () {
20 | if (! bme . performReading () ) return ;
21 | Serial . print (" Temp :␣"); Serial . print ( bme . temperature ) ; Serial . println ("␣C") ;
22 | Serial . print (" Pressure :␣") ; Serial . print ( bme . pressure / 100.0) ; Serial . println ("␣ hPa ") ;
23 | Serial . print (" Humidity :␣") ; Serial . print ( bme . humidity ); Serial . println ("␣%");
24 | Serial . print (" Gas :␣") ; Serial . print ( bme . gas_resistance / 1000.0) ; Serial . println ("␣ KOhms ") ;
25 | delay (2000) ;
26 | }

Error Analysis:

* Potential errors: Temperature Sensor, Humidity Sensor, and Barometer Sensor errors. * Mitigation: Regular calibration,

sensor shielding, cross-validation with other readings.

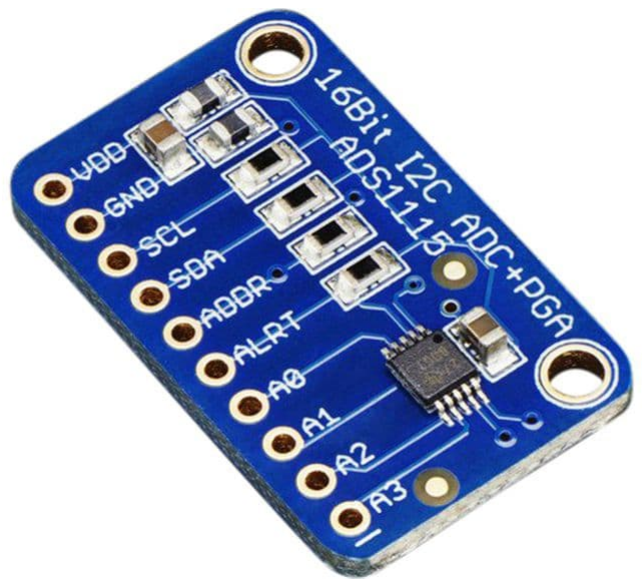
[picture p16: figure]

Figure 21: ADS1115

### 7.4.5 ADS1115 Analog-to-Digital Converter

Based on our initial selection, we are using the ADS1115- Analog To Digital Converter. Further testing and

verification details follow:

Reasons for Selection | High precision (16-bit), low power, I2C interface, and PGA for small-signal accuracy. Compact and supports a wide voltage range.
Key Specs (Datasheet Values) | • Resolution: 16 bits • Input Channels: 4 single-ended or 2 differential • Data Rate: 8 to 860 SPS (Programmable) • Operating Temperature: -40°C to +125°C • Power Consumption: 150 µA (Continuous Conversion) • Programmable Gain (PGA): ±6.144V, ±4.096V, ±2.048V, ±1.024V, ±0.512V, ±0.256V

Testing Performed:

S. No | Test | Description
1 | Accuracy Test: | Measured known voltage sources (e.g., 1.0V, 2.5V, 3.3V) and compared them with ADS1115 readings to evaluate measurement precision.
2 | Noise Test: | Analyzed noise levels at different data rates to determine the optimal configuration for stable and accurate readings.
3 | Gain Test: | Verified Programmable Gain Amplifier (PGA) settings by testing with low-voltage signals and checking for correct amplification.
4 | Power Consumption Test: | Measured current draw in different operating modes to assess efficiency for battery-powered applications.
5 | I2C Communication Test: | Ensured stable and reliable data transfer between ADS1115 and ESP32 by testing various communication speeds and conditions.

Testing Results:

Parameter | Value
Voltage Measurement Error (3.3V input) | ±0.05V
Voltage Measurement Error (5V input) | ±0.07V
Noise Level (PGA Gain = 1) | 3 LSB (≈ 0.2mV)
Noise Level (PGA Gain = 16) | 5 LSB (≈ 0.05mV)
Max Achieved Sampling Rate | 859 samples/sec

Table 8: ADS1115 Testing Results

Integration Details:

The AHT21B connects to the ESP32 via I2C with pull-up resistors, powered by 3.3 V, and uses the Adafruit AHTX0 library for

data parsing.

Code Snippet:

1 | # include < Wire .h >
2 | # include < Adafruit_ADS1015 .h >

3

4 Adafruit_ADS1015 ads ;

5

void setup ( void ) {

Serial . begin (9600) ;

ads . begin () ;

}

void loop ( void ) {

for (int i = 0; i < 4; i ++) {

int16_t adc = ads . readADC_SingleEnded (i) ;

float volts = ads . computeVolts ( adc );

Serial . print (" AIN "); Serial . print ( i); Serial . print (":␣") ;

Serial . print ( adc ) ; Serial . print ("␣"); Serial . print ( volts );

Serial . println ("V");

}

Serial . println (" --------------------");

delay (1000) ;

}

Error Analysis:

* Potential errors: calibration offsets, temperature drift, environmental factors, and voltage variance.

* Mitigation strategies: proper calibration, temperature compensation, and power supply regulation.

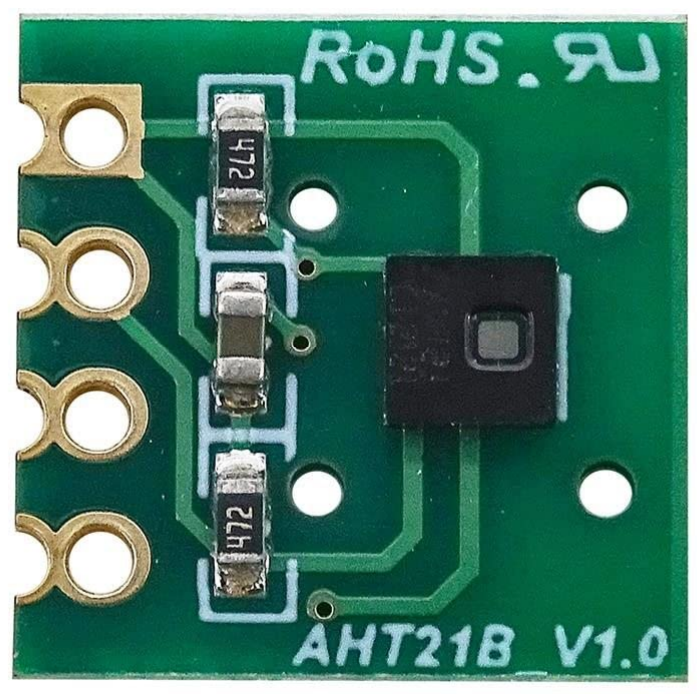
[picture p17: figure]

Figure 22: AHT21B

### 7.4.6 AHT21B

Based on our initial selection, we are using the AHT21B. Further testing and verification details follow:

Reasons for Selection High accuracy, digital I2C output, low power consumption, compact size, wide operating range.

Key Specs (Datasheet
Values) | • Temperature Range: -40°C to +85°C
| • Humidity Range: 0% to 100% RH
| • Humidity Accuracy:±2% RH
| • Temperature Accuracy: ±0.3°C
| • Resolution: Temperature: 0.01°C, Humidity: 0.024% RH
| • Supply Voltage: 2.2V to 5.5V
| • Operating Current: 0.25 mA
| • Response Time: 8 sec (humidity), 5 sec (temperature)

Testing Performed:

S. No | Component | Purpose
1 | Accuracy Tests: | The sensor’s readings were compared to calibrated reference values under controlled indoor and outdoor conditions. Measurements were taken over time to assess deviations. The test ensured precise temperature and humidity tracking.
2 | Noise Test: | The sensor was kept in a stable environment, and data was recorded to detect fluctuations. Any random variations were analyzed to evaluate output stability. The goal was to minimize noise interference.
3 | Temperature & Hu-midity Test: | The sensor was tested across varying temperatures and humidity levels using controlled heating, cooling, and moisture chambers. Readings were compared to reference thermometers and hygrometers.

Testing Results:

Parameter | Value
Temperature Test(25-50°C) | ±0.04°C
Humidity Test (50%-80% RH) | ±0.3% RH
Noise Test | ±0.1°C, ±0.5% RH

Integration Details: The AHT21B sensor is connected to the ESP32 via I2C, powered by 3.3V, with 4.7kω pull-up resistors.

The Adafruit AHTX0 library is used for temperature and humidity data parsing.

Code Snippet:

1 | # include < Wire .h >
2 | # include < AHT20 .h >

3

4 AHT20 aht20 ;

5

6 | void setup () {
7 | Serial . begin (115200) ;
8 | while (! Serial );
9 | Serial . println (" Starting ... ");
10 | Wire . begin () ;

if (! aht20 . begin () ) {

Serial . println (" AHT20 ␣ not␣ detected .␣ Check ␣ wiring .");

while (1) ;

}

}

void loop () {

if ( aht20 . available () ) {

Serial . print (" Temp :␣"); Serial . print ( aht20 . getTemperature () , 2) ;

Serial . print ("␣C␣␣ Humidity :␣"); Serial . print ( aht20 . getHumidity () , 2) ;

Serial . println ("%␣RH") ;

}

delay (2000) ;

}

Error Analysis: Potential errors include minimal quantization, ±0.1°C noise, ±0.5% RH noise, ±0.1°C temperature drift,

and ±1

Calibration Procedures: We perform offset calibration by measuring reference conditions (0% RH, 0°C) and adjusting

readings accordingly. Gain calibration is applied using known references (100% RH, 100°C), and temperature compensation is

implemented if needed to maintain accuracy.

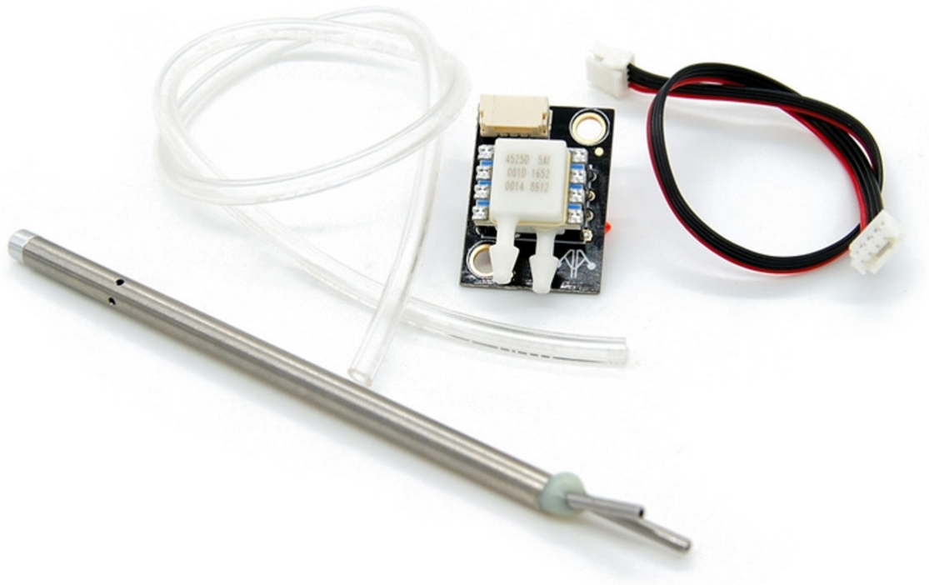
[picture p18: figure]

Figure 23: MS4525DO Air Speed

### 7.4.7 Airspeed Sensor - MS4525DO

Based on our initial selection, we are using the MS4525DO differential pressure sensor. Further testing and

verification details follow:

Reasons for Selection | High-resolution differential pressure sensing for airspeed measurement, good documentation, compatibility with ESP32, digital output (I2C/SPI), compact form factor, and low power consumption.
Key Specs (Datasheet Values) | • Interface: I2C (max 400 kbit s⁻¹ ) / SPI • Pressure Range: −1 ψ to 1 ψ (± 6.9 kPa) • Resolution: 14-bit (pressure), 11-bit (temperature) • Accuracy: ±0.25% Full Scale Span (FSS) • Power requirements: 3.3 V to 5.0 V • Current Draw: 2.5 mA (typical) • Weight: 10 g

Testing Performed:

S. No | Test | Procedure
1 | Zero Offset Measure-ment: | The sensor was exposed to ambient pressure, and the raw output was recorded over 10 min to check for initial zero offset.
2 | Linearity Test: | Known pressure values were applied using a calibrated pres-sure source, and the sensor output was recorded to verify linear response.
3 | Temperature Stability: | The sensor was subjected to temperature variations be-tween 0 ◦C and 50 ◦C while monitoring drift in pressure readings.

Testing Results:

Parameter | Value
Zero Offset | ± 0.1% FSS
Linearity Error | ± 0.25% FSS
Temperature Drift | ± 0.5% FSS over 50 ◦C range
Response Time | 1 ms

Table 9: MS4525DO Testing Results

Calibration: A two-point calibration is performed at zero pressure (ambient) and a known reference pressure using a digital

manometer. The resulting offset and scale factors are applied to correct raw sensor readings.

Integration Details: The MS4525DO sensor is connected to the ESP32 via the I2C interface . The sensor is mounted in a

ventilated compartment to minimize temperature fluctuations.

Code Snippet:

1 # include < Wire .h >

2

3 # define MS4525DO_ADDR 0 x28

4

5 | void setup () {
6 | Serial . begin (115200) ;

Wire . begin () ;

}

void loop () {

Wire . beginTransmission ( MS4525DO_ADDR );

Wire . write (0 x00 ) ;

Wire . endTransmission () ;

Wire . requestFrom ( MS4525DO_ADDR , 2) ;

if ( Wire . available () == 2) {

uint16_t rawData = ( Wire . read () << 8) | Wire . read () ;

float pressure = (( rawData - 8192) * (2.0 / 16384.0) ) * 6.89476; // Convert to kPa

Serial . println (" Pressure :␣" + String ( pressure ) + "␣ kPa ");

}

delay (500) ;

}

Error Analysis: Potential sources of error include sensor offset drift, temperature sensitivity, and electrical noise. Mitigation

strategies include periodic calibration, temperature compensation, and filtering techniques.

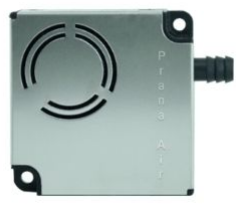
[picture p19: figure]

Figure 24: Prana PAS-01

### 7.4.8 Air Quality Sensor - Prana PAS-01 Outdoor

Based on our initial selection, we are using the Prana PAS-01 Outdoor air quality sensor. Further testing and

verification details follow:

Reasons for Selection | High-accuracy air quality sensing, multiple pollutant detection (PM2.5, PM10, CO2, NO2,O3), industrial-grade reliability, low maintenance, and compatibility with microcontrollers (ESP32, Raspberry Pi).
Key Specs (Datasheet Values) | • Measured Parameters: PM1.0, PM2.5, PM10, CO2, NO2,O3, temperature, humidity • Communication: UART (RS485 Modbus), WiFi, LTE options • Accuracy: ±10% for PM, ±50 ppm for CO2, ±5% for humidity • Operating Temperature: −20 ◦C to 50 ◦C • Power Requirements: 5 V (USB) or external 12 V DC • Enclosure: IP65-rated (weatherproof) • Weight: 250 g

Testing Performed:

S. No | Test | Procedure
1 | Baseline Calibration: | The sensor was placed in a controlled indoor environment, and initial readings were compared with reference instru-ments.
2 | Outdoor Exposure Test: | The sensor was deployed outdoors for 48 h to validate long-term stability and detect environmental interference.
3 | Response Time Check: | A controlled air sample with elevated PM2.5 levels was in-troduced to observe sensor response time.
4 | Humidity Impact: | The sensor was tested under varying humidity levels to check measurement drift.

Testing Results:

Parameter | Value
Baseline Accuracy (PM2.5) | ± 8% (compared to reference)
Response Time | 10 s (PM), 30 s (gas)
Humidity Influence | ± 3% deviation in high-humidity conditions
Outdoor Stability | Less than ± 5% drift over 48 hours

Table 10: Prana PAS-01 Outdoor Testing Results

Calibration: The sensor was calibrated using co-located reference-grade air quality monitors. A multi-point correction

factor was applied based on statistical regression analysis.

Integration Details: The PAS-01 sensor communicates with the ESP32 via UART (RS485). It is mounted in an open-air

enclosure with a rain shield to prevent direct water exposure.

Code Snippet:

1 # include < SoftwareSerial .h >

2

3 SoftwareSerial pas01 (16 , 17) ; // RX , TX

4

5 void setup () {

Serial . begin (115200) ;

pas01 . begin (9600) ;

}

void loop () {

if ( pas01 . available () ) {

String data = pas01 . readStringUntil (’\n’);

Serial . println (" Sensor ␣ Data :␣" + data );

}

delay (2000) ;

}

Error Analysis: Potential sources of error include humidity-induced drift, sensor aging, and interference from nearby

pollution sources. Error mitigation involves periodic recalibration, housing design adjustments, and real-time data filtering.

Figure 25: M135

### 7.4.9 Gas Sensor - M135

Based on our initial selection, we are using the M135 gas sensor. Further testing and verification details follow:

Reasons for Selection | High-sensitivity gas detection for CO, CO2, NH3, and other
| volatile organic compounds (VOCs). Suitable for air quality
| monitoring applications, good response time, easy integration
| with microcontrollers, and low power consumption.

Key Specs (Datasheet
Values) | • Measured Gases: CO, CO2, NH3, VOCs
| • Operating Voltage: 5 V DC
| • Sensitivity: 10-1000 ppm (CO), 100-10000 ppm (NH3)
| • Response Time: <30 s
| • Warm-up Time: <60 s
| • Communication: Analog output
| • Power Consumption: 150 mW
| • Operating Temperature: −10 ◦C to 50 ◦C
| • Weight: 15 g

Table 11: Specifications of the M135 Gas Sensor

Testing Performed:

S. No | Test | Procedure
1 | Baseline Measure-ment: | The sensor was exposed to ambient air for 5 min to establish a reference baseline.
2 | Gas Sensitivity Test: | The sensor was placed in a controlled chamber with known concentrations of CO and NH3 to measure response accu-racy.
3 | Response Time Check: | A sudden introduction of CO was used to observe the sen-sor’s response time and recovery period.
4 | Temperature Stability: | The sensor was exposed to varying temperatures from −10 ◦C to 50 ◦C to evaluate drift in gas readings.

Table 12: Testing Procedures for M135

Testing Results:

Parameter | Value
Baseline Drift | ± 5% over 24 h period
Sensitivity Accuracy | ± 10% (compared to reference values)
Response Time | <30 s
Temperature Influence | ± 4% deviation over full range

Table 13: M135 Gas Sensor Testing Results

Calibration: The sensor is calibrated using known gas concentrations and a linear regression model. Periodic recalibration

is recommended to maintain accuracy.

Integration Details: The M135 sensor is connected to an ESP32 microcontroller via an analog input pin. A voltage divider

circuit is used to scale the sensor output appropriately.

Code Snippet:

1 # define SENSOR_PIN A0

2

3 void setup () {

4 | Serial . begin (115200) ;
5 | }

6

7 | void loop () {
8 | int sensorValue = analogRead ( SENSOR_PIN );
9 | float voltage = sensorValue * (5.0 / 1023.0) ;
10 | Serial . println (" Gas ␣ Sensor ␣ Voltage :␣" + String ( voltage ) + "V");

11

12 | delay (1000) ;
13 | }

Error Analysis: Potential sources of error include sensor aging, humidity effects, and interference from other gases. Error

mitigation includes frequent calibration, using a temperature-compensated model, and data smoothing techniques.

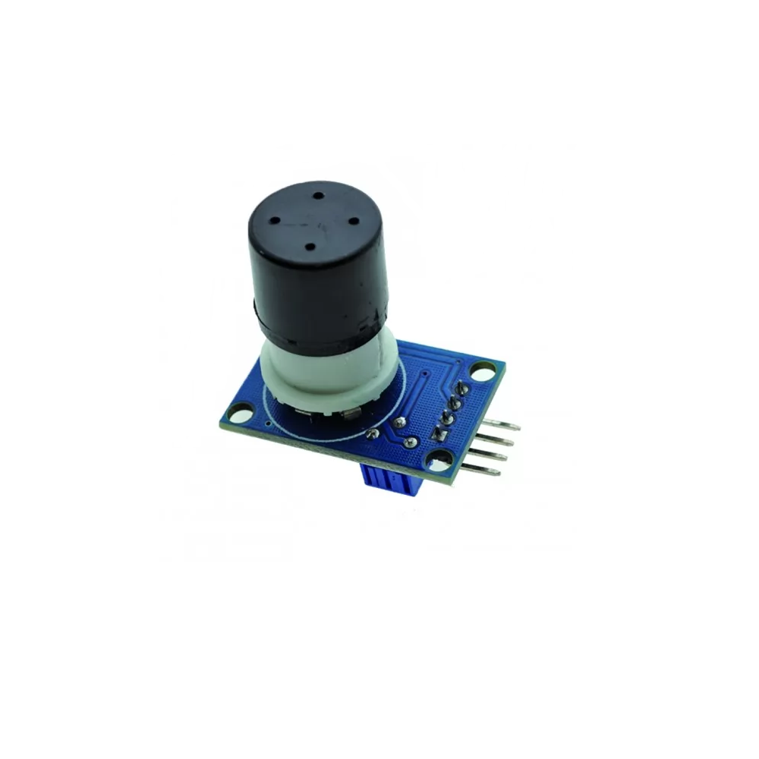
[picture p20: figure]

Figure 26: MQ131

### 7.4.10 Gas Sensor - MQ131

Based on our initial selection, we are using the MQ131 gas sensor module. Further testing and verification

details follow:

Reasons for Selection | Need a reliable gas sensor to detect ozone (O3) concentrations in
| the environment. Low power consumption, ease of use, and
| availability of breakout boards.

Key Specs (Datasheet
Values) | • Sensor Type: Metal Oxide Semiconductor (MOS) sensor
| • Detection Target: Ozone (O3)
| • Operating Voltage: 5 V
| • Current Draw: 150 mA (when heating)
| • Preheating Time: 24 hours for initial calibration
| • Resistance Range: 10 kΩ to 100 kΩ (depending on gas
| concentration)
| • Response Time: 30 seconds (for detection)
| • Weight: 20 g

Testing Performed:

S. No | Test | Procedure
1 | Response Time Test: | We measured the time taken by the sensor to respond to ozone gas exposure by introducing known concentrations of ozone and observing the sensor output.
2 | Sensor Calibration: | We calibrated the sensor in a controlled environment by exposing it to different ozone concentrations and recording the sensor resistance.
3 | Noise Measurements: | We observed the noise level of the sensor in a stable envi-ronment with no gas exposure for 10 min.

Testing Results:

Parameter | Value
Sensor Response Time (to O3) | 30 seconds (typical)
Gas Concentration Range | 10 ppb to 1 ppm
Heater Resistance (for 5V) | 33 Ω
Gas Sensitivity (toO3) | 10 kΩ to 100 kΩ depending on concentration
Noise Level (no gas) | Minimal noise, stable resistance under no gas exposure
Calibration Sensitivity (O3) | Linear with ozone concentration (within 10-1000 ppb range)

Table 14: MQ131 Testing Results

Error Analysis: Potential sources of error include sensor drift over time, temperature and humidity variations, and incon-

sistent gas exposure. To mitigate these errors, we are using a calibration procedure and environmental compensations (such as

humidity sensors) to ensure accurate readings.

Integration Details: The MQ131 sensor is connected to the microcontroller (e.g., ESP32) via an analog input pin. It

requires a heater circuit for its operation, and its output is measured through a voltage divider connected to an ADC (Analog-

to-Digital Converter). The sensor is mounted on the central PCB.

Code Snippet:

1 int mq131Pin = A0 ; // Analog input pin for MQ131 sensor

2

void setup () {

Serial . begin (115200) ;

}

void loop () {

int sensorValue = analogRead ( mq131Pin );

float ozoneConcentration = calculateOzoneConcentration ( sensorValue );

Serial . println (" Ozone ␣ Concentration :␣" + String ( ozoneConcentration ) + "␣ ppb ") ;

delay (1000) ;

}

float calculateOzoneConcentration ( int sensorValue ) {

// Simple linear approximation for concentration

return ( sensorValue / 1023.0) * 1000.0; // Assume linear relationship

}

Sensor Fusion: While the MQ131 sensor provides valuable data on ozone levels, we may fuse this information with other

environmental data (e.g., temperature, humidity) to improve the overall accuracy of air quality monitoring. This could be done

using a Kalman filter or other sensor fusion techniques.

Future Enhancements: Future work will involve implementing a more precise calibration model for the MQ131 sensor,

along with the integration of a real-time clock (RTC) for time-stamped data collection.

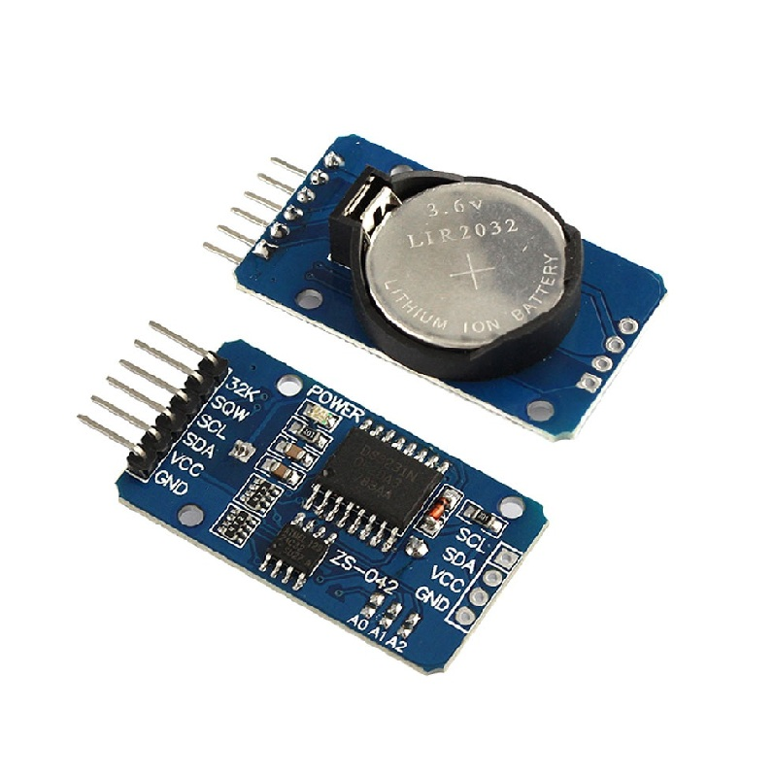
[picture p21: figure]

Figure 27: RTC

### 7.4.11 DS3231 - Real-Time Clock Module

Based on our initial selection, we are using the DS3231 RTC module. Further testing and verification details

follow:

Reasons for Selection | High accuracy, I2C interface, Low power consumption, Easy integration with ESP32, Real-time
| clock functionality

Key Specs (Datasheet
Values) | • Accuracy: ± 2 minute per year
| • Supply Voltage: 2.3 V to 5.5 V
| • Power Consumption:
| – Operating Mode: 1.0 mA
| – Standby Mode: 0.075 mA
| • Temperature Range: - 40 ◦C to 85 ◦C
| • Weight: 3.5 g
| • Interface: I2C

Testing Performed:

S. No | Component | Purpose
1 | Accuracy Tests: | We compared the time kept by the DS3231 module against a reference clock. The test was conducted over a 24-hour period, checking for drift in the clock’s accuracy.
2 | Power Consumption Measurements: | The current draw of the DS3231 was measured using a multimeter in series with the power supply during both operating and standby modes.
3 | Temperature Depen-dence Test: | The DS3231’s performance was tested at various temperatures within its operating range. The temperature was varied from - 40 ◦C to 85 ◦C to observe any drift in accuracy.

Testing Results:

Parameter | Value
Accuracy (Time Drift) | 1.5 minute per year (Average over 24 h)
Power Consumption (Operating Mode) | 1.0 mA
Power Consumption (Standby Mode) | 0.075 mA
Temperature Range Tested | - 40 ◦C to 85 ◦C

Integration Details: The DS3231 module is connected to the ESP32 via I2C. The SDA and SCL pins are connected to

GPIO21 and GPIO22, respectively, of the ESP32. The module is mounted on the top plate of the CanSat.

Code Snippet:

1 | # include < Wire .h >
2 | # include < RTClib .h >

3

4 RTC_DS3231 rtc ;

5

6 | void setup () {
7 | Serial . begin (9600) ;

8

9 | // Check if the RTC is connected properly
10 | if (! rtc . begin () ) {
11 | Serial . println (" Couldn ’t␣ find ␣ RTC ");
12 | while (1) ;
13 | }

14

15 | // Check if the RTC lost power
16 | if ( rtc . lostPower () ) {
17 | // Set the time to the compile time
18 | rtc . adjust ( DateTime ( F( __DATE__ ) , F( __TIME__ ))) ;
19 | }
20 | }

21

22 | void loop () {
23 | DateTime now = rtc . now () ;

24

25 | Serial . print (" Date / Time :␣");
26 | Serial . print ( now . year () , DEC ) ;
27 | Serial . print (’/’);
28 | Serial . print ( now . month () , DEC );
29 | Serial . print (’/’);
30 | Serial . print ( now . day () , DEC );
31 | Serial . print ("␣");
32 | Serial . print ( now . hour () , DEC ) ;
33 | Serial . print (’:’);
34 | Serial . print ( now . minute () , DEC );
35 | Serial . print (’:’);
36 | Serial . print ( now . second () , DEC );
37 | Serial . println () ;

38

39 | delay (1000) ; // Update every second
40 | }

Error Analysis: Potential sources of error include temperature fluctuations, power supply variations, and I2C communica-

tion issues. The DS3231 is quite accurate, but external factors may still contribute to minor discrepancies.

Calibration Procedures: The DS3231 module is factory-calibrated for time accuracy. No specific calibration is required;

however, the initial setup synchronizes the time based on the system’s compile time.
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

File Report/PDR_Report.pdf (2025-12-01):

# IN-SPACe CANSAT India Student Competition 2024-25 (2nd Edition)

# Preliminary Design Review (PDR)

## 2024-ASI-CANSAT-044-BRAHMAND

# Index

Sr No | Sections | Page No.
1 | Introduction | 1-1
2 | Team Organization | 2-4
3 | System Overview | 5-23
4 | Sensor Subsystem Overview | 24-36
5 | Payload Subsystem Overview | 37-40
6 | Communication and Data Handling | 41-54
7 | Electrical Power Design | 55-57
8 | Flight Software design | 57-63
9 | Ground control system | 64-65
10 | Descent Control design | 66-77
11 | Mechanical Subsystem design | 78-91
12 | Deployment Mechanism design | 92-94
13 | Mechanical stabilization system | 95-102
14 | Power Budget | 103-104
15 | Mass Budget | 105-108
16 | Hardware Budget | 109-111
17 | Integration and testing | 112-115
18 | Mission Operation and analysis | 116-117
19 | Location and recovery | 118 -120
20 | Program Schedule | 121-124
21 | Conclusion | 125-126
22 | Appendix | 127-131

# Team Organization
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

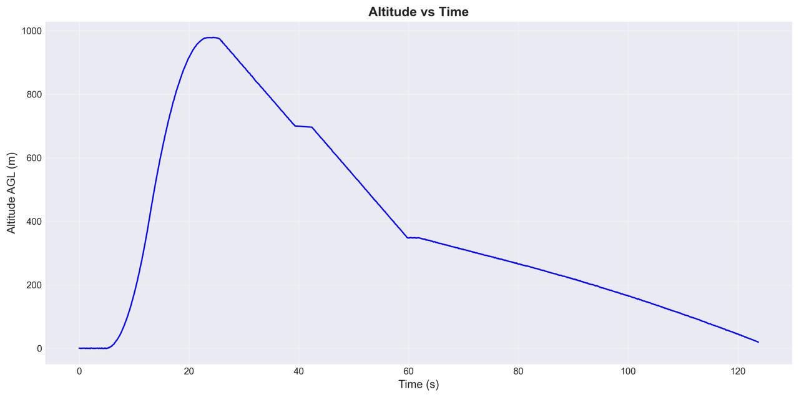
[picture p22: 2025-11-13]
Data-collected/WhatsApp Image 2025-11-07 at 16.43.04_f264e52f.jpg

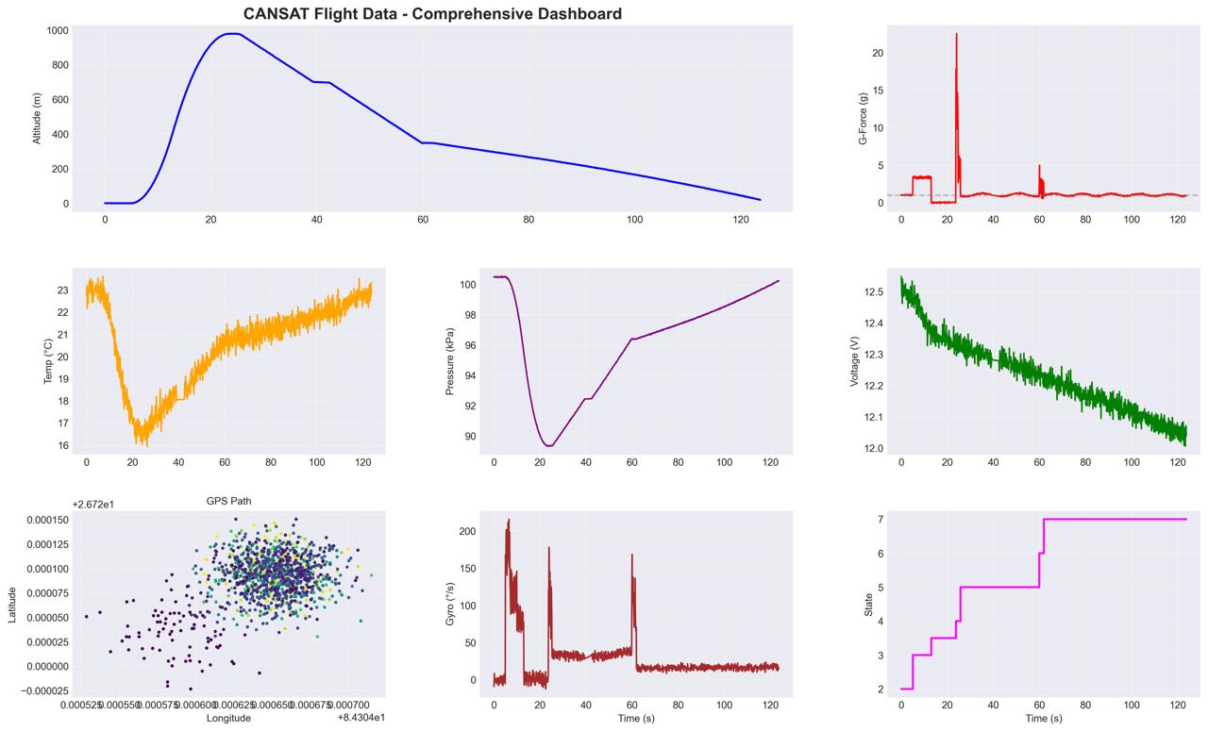
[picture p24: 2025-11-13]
Data-collected/WhatsApp Image 2025-11-07 at 16.43.02_a5faa6ee.jpg

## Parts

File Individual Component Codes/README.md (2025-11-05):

# Individual-Sensor-Codes
Repo with all the individual sensors tested on ESP32

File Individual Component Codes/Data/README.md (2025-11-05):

# Data (SD Card)

This project provides an Arduino sketch to benchmark the performance and verify the data integrity of an SD card with an ESP32. The script performs a sustained write-read-verify cycle, making it a useful tool for evaluating SD card suitability for data logging applications.

The script repeatedly performs the following cycle:

1.  **Generates** 20 lines of sample CSV data in memory.
2.  **Writes** this data to a file on the SD card as quickly as possible and measures the write speed.
3.  **Reads** the data back from the file and measures the read speed.
4.  **Verifies** that the data read from the card exactly matches the original data, reporting a pass or fail status.

## Hardware Requirements

  * An ESP32 Development Board
  * A MicroSD Card Module (with SPI interface)
  * A FAT32-formatted MicroSD Card
  * Jumper Wires

-----

## Software & Libraries

  * **Arduino IDE** with the [ESP32 board manager](https://docs.espressif.com/projects/arduino-esp32/en/latest/installing.html) installed.
  * **SPI.h** (Included with the ESP32 core)
  * **SD.h** (Included with the ESP32 core)

-----

## Wiring 🔌

The test uses the ESP32's default **VSPI** (Virtual SPI) pins.

| SD Card Pin | ESP32 Pin |
| :--- | :--- |
| **CS** | **GPIO 5** |
| **SCK** | **GPIO 18** |
| **MISO** | **GPIO 19** |
| **MOSI** | **GPIO 23** |
| **VCC** | **3.3V** |
| **GND** | **GND** |

-----

## Installation & Usage

1.  **Format SD Card**: Ensure your MicroSD card is formatted with a **FAT32** file system.
2.  **Connect Hardware**: Wire the SD card module to your ESP32 according to the pinout table above.
3.  **Upload Code**: Open the `.ino` sketch in the Arduino IDE, select your ESP32 board and port, and upload the code.
4.  **Monitor Output**: Open the **Serial Monitor** and set the baud rate to **115200**. The test will start automatically and repeat every 5 seconds.

-----

## Expected Output

The Serial Monitor will display the results for each test cycle, showing the write/read speeds and the final data integrity status.

```
Initializing SD card...initialization done.
Generating test data...

--- Starting Write Test ---
Wrote 20 lines in 15 ms.
Write Speed: 1333.33 lines/second.

--- Starting Read & Verification Test ---
Read and verified 20 lines in 2 ms.
Read Speed: 10000.00 lines/second.
✅ Data Integrity: PASSED

---------------------------------
Test cycle complete. Starting new test in 5 seconds...
```

If the data read from the card does not match the original data, the test will immediately fail and print the mismatched lines:

```
--- Starting Read & Verification Test ---
!!! DATA MISMATCH! !!!
Original Data: 12345,42.10,1013.25,10
Data from SD : 12345,42.10,1013.25,1
Read and verified 11 lines in 1 ms.
Read Speed: 11000.00 lines/second.
❌ Data Integrity: FAILED
```

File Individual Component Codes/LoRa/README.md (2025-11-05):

# LoRa-Comms
Working Comms. Nobody touch without permission.

- CanSat code sends data at 1 seconds intervals
    - Can receive commands from the ground station
- Ground station commands can be sent from the terminal

The python part is not tested yet.

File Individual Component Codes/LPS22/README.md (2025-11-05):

# LPS22

This repository contains a simple test sketch for using the LPS22 pressure sensor with an ESP32 via the I2C protocol. This guide clarifies the specific wiring for boards that use `SCK`, `SDI`, and `SDO` pin labels for I2C communication.

## Libraries Needed

To use this sensor, you must install the following libraries through the Arduino IDE Library Manager:

  * `Adafruit LPS2X`
  * `Adafruit Unified Sensor`
  * `Adafruit BusIO`

## Pinout and Wiring

This sensor uses I2C communication. Connect the pins to your ESP32 as follows.

| LPS22 Pin | ESP32 Pin | Description |
| :--- | :--- | :--- |
| **VIN** | **3.3V** | Power |
| **GND** | **GND** | Ground |
| **SCK** | **GPIO 22** | I2C Clock (`SCL`)  |
| **SDI** | **GPIO 21** | I2C Data (`SDA`) |

**Important Note on Pin Names:**
Some breakout boards, like the one this guide is based on, use non-standard names for I2C pins:

  * **SCK** is used for the I2C clock line (connect to `SCL`).
  * **SDI** is used for the I2C data line (connect to `SDA`).
  * **SDO** is **not** for data; it is the **I2C Address selector pin**. See the "Notes" section for details.

-----

## Expected Output

After uploading the code, open the Arduino Serial Monitor with the baud rate set to **115200**. You should see the following output, updating every second:

```
LPS22 Test using I2C
LPS22 Found!
Temperature: 26.50 C
Pressure: 1012.34 hPa

Temperature: 26.51 C
Pressure: 1012.33 hPa

...
```

-----

## Notes

  * **I2C Address**: The LPS22 has a default I2C address. On boards with an `SDO` pin, you can change this address.
      * Leave `SDO` **unconnected** for the default address (often `0x5D`).
      * Connect `SDO` to **GND** to switch to the alternate address (`0x5C`).
  * **3.3V Logic**: The sensor is a 3.3V device, which is perfectly compatible with the ESP32's logic level.

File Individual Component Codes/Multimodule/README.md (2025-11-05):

# Multimodule

This repository contains a test sketch for the Bosch BME680, a 4-in-1 environmental sensor that measures temperature, humidity, barometric pressure, and volatile organic compounds (VOCs) for air quality monitoring. This guide provides the necessary code and wiring instructions for use with an ESP32 via the I2C protocol.

## Libraries Needed

You must install the following libraries through the Arduino IDE Library Manager (**Sketch** -\> **Include Library** -\> **Manage Libraries...**) to use this sensor:

  * `Adafruit BME680 Library`
  * `Adafruit Unified Sensor`
  * `Adafruit BusIO`

-----

## ESP32 Pinout

The BME680 is a 3.3V device, making it directly compatible with the ESP32's power and logic levels. Connect the sensor using the default I2C pins.

| BME680 Pin | ESP32 Pin |
| :--- | :--- |
| **VIN** | **3.3V** |
| **GND** | **GND** |
| **SCL** | **GPIO 22** |
| **SDA** | **GPIO 21** |

-----

## Expected Output

After uploading the code, open the Arduino Serial Monitor with the baud rate set to **115200**. You should see a continuous stream of data updating every two seconds:

```
BME680 Test
Temperature = 25.40 *C
Pressure = 1013.25 hPa
Humidity = 45.50 %
Gas = 50.12 KOhms
Approx. Altitude = 0.00 m

...
```

-----

## Notes

  * **I2C Address**: The default I2C address for the BME680 is **0x77**. If the scanner or code fails to find it, check if your board has an address jumper that might have it set to the alternate address, **0x76**.
  * **Gas Sensor (VOC)**: The gas sensor reading is given in Ohms of resistance. It does not measure a specific gas but rather the total concentration of Volatile Organic Compounds (VOCs).
      * **Higher resistance** generally indicates **cleaner air**.
      * **Lower resistance** indicates the presence of pollutants like ethanol, acetone, or carbon monoxide.
  * **Warm-up Period**: The gas sensor requires a "burn-in" period to achieve stable readings. For the first use, let it run for several minutes. For high-accuracy applications, a burn-in of up to 20 minutes is recommended by Bosch.

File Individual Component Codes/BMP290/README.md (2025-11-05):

# BMP290

Auto-created README for BMP290.

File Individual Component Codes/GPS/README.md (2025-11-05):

# GPS

Auto-created README for GPS.

-- MODULE: U-blox Neo M8N

-- LIBRARY: Tiny GPS PLUS

____

Non A-GPS version

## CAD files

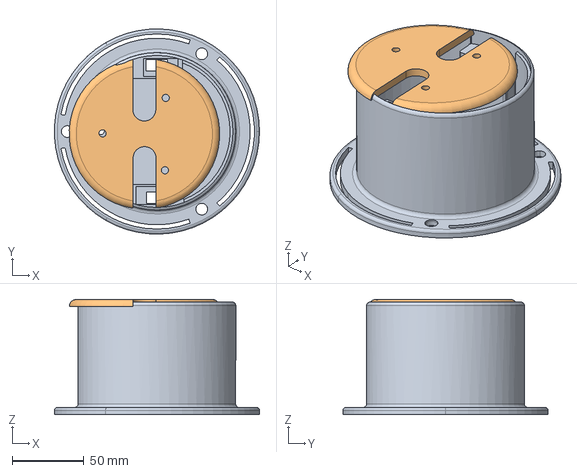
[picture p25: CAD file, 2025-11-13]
3D CAD Models/parachute_compartment_final.step
142.9 x 143.0 x 80.3 mm

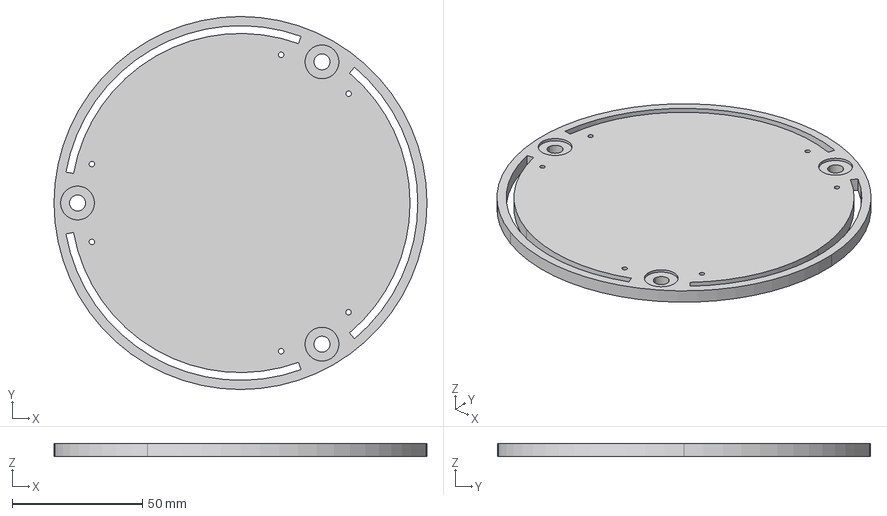
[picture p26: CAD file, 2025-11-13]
3D CAD Models/section_divider_final.step
143.0 x 143.0 x 5.00 mm

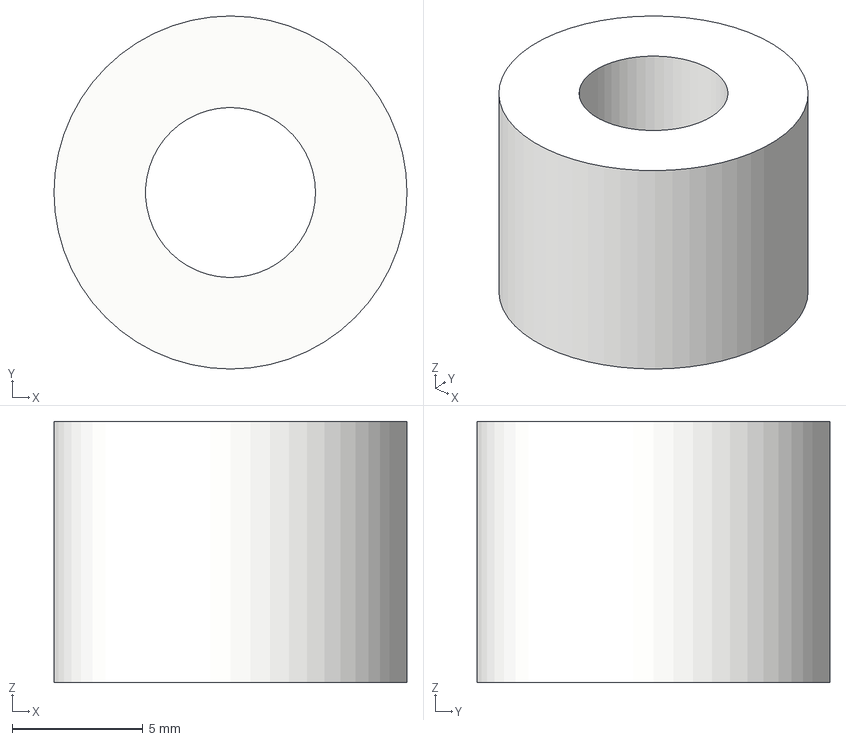
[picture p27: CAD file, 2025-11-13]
3D CAD Models/spacer_final.step
13.5 x 13.5 x 10.0 mm

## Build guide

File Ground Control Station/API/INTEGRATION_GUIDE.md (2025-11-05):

# 🚀 ESP32 + Python API Integration Guide

## 📋 Quick Summary

You now have **two working systems**:

### 🎲 **main.py** (Port 8001) - Random Data
- **Purpose**: Testing & development with simulated data
- **Use when**: No hardware available, testing GUI, demonstrations

### 📡 **parser.py** (Port 8002) - Real ESP32 Data  
- **Purpose**: Live data from your ESP32 hardware
- **Use when**: Connected to real ESP32 CanSat device

---

## 🔧 **Setup Steps**

### 1. **Upload ESP32 Code**
- Upload the updated `ESP_GCS.ino` to your ESP32
- Make sure `#define CANSAT_MODE` is uncommented
- The code now sends: `PING:Packet:123,TS:54321,Alt:150.5,Temp:25.3,...`

### 2. **Install Dependencies**
```bash
cd /Users/va/GCS-3D/API
pip install -r requirements.txt
```

### 3. **Find Your ESP32 Port**
```bash
python find_ports.py
# Look for ports with "CP2102" or "Silicon Labs" in description
# Likely ports: /dev/cu.usbserial-* or /dev/cu.SLAB_USBtoUART
```

### 4. **Start the Parser API**
```bash
./start.sh
# Choose option 2: Parser API (Serial Data)
```

### 5. **Connect to ESP32**
The API will show available ports on startup. Connect via:
- API endpoint: `POST /serial/connect` with your port
- Or use the helper: `python connect_esp32.py`

---

## 📊 **Port Connection Logging**

The parser now shows **detailed connection information**:

```
============================================================
🔌 ATTEMPTING SERIAL CONNECTION
============================================================
📍 Port: /dev/cu.usbserial-0001
⚡ Baud Rate: 115200
============================================================
🔗 Opening serial connection...
✅ SERIAL CONNECTION SUCCESSFUL!
📡 Connected to: /dev/cu.usbserial-0001  
⚡ Baud rate: 115200
🎯 Status: ACTIVE - Listening for data...
============================================================
```

---

## 🧪 **Testing & Verification**

### Test Format Compatibility:
```bash
python simple_test.py
```

### Quick ESP32 Connection:
```bash  
python connect_esp32.py
```

### Find Available Ports:
```bash
python find_ports.py
```

---

## 📡 **Expected Data Flow**

1. **ESP32 sends**: `PING:Packet:123,TS:54321,Alt:150.5,Temp:25.3,Pressure:1015.2,Lat:28.6140,Lon:77.2095,Voltage:3.3,State:1`

2. **Parser receives & logs**: 
   ```
   <<< Received Telemetry: PING:Packet:123,TS:54321,Alt:150.5,...
   ```

3. **API converts to JSON**:
   ```json
   {
     "timestamp": 1696291200,
     "altitude": 150.5,
     "temperature": 25.3,
     "pressure": 1015.2,
     "battery": 47.1,
     "gnss": {"lat": 28.6140, "lng": 77.2095},
     "system_state": 1
   }
   ```

4. **GUI fetches**: `GET http://localhost:8002/telemetry`

---

## 🔍 **Troubleshooting**

### **"No ports found"**
- Check USB connection to ESP32
- Install ESP32 drivers (CP2102/Silicon Labs)
- Try different USB cables/ports

### **"Port in use"** 
- Close Arduino IDE or other serial monitors
- Disconnect other applications using the port

### **"No data received"**
- Verify ESP32 is in `CANSAT_MODE`
- Check baud rate (115200)
- Confirm ESP32 is running and sending data

### **Wrong data format**
- Upload the updated `ESP_GCS.ino` code
- Check ESP32 serial monitor output matches expected format

---

## 🌐 **API Endpoints**

| Endpoint | Method | Purpose |
|---|---|---|
| `/telemetry` | GET | Get latest telemetry data |
| `/serial/ports` | GET | List available serial ports |
| `/serial/connect` | POST | Connect to ESP32 port |
| `/serial/status` | GET | Check connection status |
| `/serial/disconnect` | POST | Disconnect from port |
| `/command` | POST | Send commands to ESP32 |

---

## 🎯 **Final Result**

- ✅ **Port connection clearly displayed**
- ✅ **ESP32 format fully compatible** 
- ✅ **Real-time data parsing working**
- ✅ **Easy port discovery tools**
- ✅ **Comprehensive logging & debugging**

Your GUI can now connect to `http://localhost:8002/telemetry` to get live data from your ESP32 CanSat! 🚀

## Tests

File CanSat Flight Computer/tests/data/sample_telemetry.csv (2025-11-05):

timestamp | mission_time | altitude | pressure | temperature | voltage | gps_lat | gps_lon | gps_alt | gyro_x | gyro_y | gyro_z | accel_x | accel_y | accel_z | state | co2_ppm | lpg_ppm
1672531200 | 0.000 | 100.5 | 1013.25 | 20.1 | 3.7 | 40.7128 | -74.0060 | 50.0 | 0.1 | -0.2 | 0.05 | 0.05 | 0.02 | 9.81 | PRELAUNCH | 412 | 0
1672531201 | 1.000 | 101.2 | 1012.8 | 20.0 | 3.7 | 40.7129 | -74.0061 | 51.2 | 0.2 | -0.1 | 0.03 | 0.04 | 0.03 | 9.82 | PRELAUNCH | 415 | 0
1672531202 | 2.000 | 102.8 | 1011.5 | 19.9 | 3.6 | 40.7130 | -74.0062 | 52.8 | 0.15 | 0.05 | 0.02 | 0.06 | 0.01 | 9.80 | LAUNCH | 418 | 0
1672531203 | 3.000 | 105.5 | 1009.2 | 19.7 | 3.6 | 40.7131 | -74.0063 | 55.5 | 0.8 | 1.2 | 0.9 | 2.1 | 1.8 | 8.5 | ASCENT | 420 | 2
1672531204 | 4.000 | 110.2 | 1005.8 | 19.4 | 3.5 | 40.7132 | -74.0064 | 60.2 | 1.5 | 2.1 | 1.2 | 4.2 | 3.1 | 7.2 | ASCENT | 425 | 5
1672531205 | 5.000 | 118.7 | 999.5 | 18.9 | 3.5 | 40.7133 | -74.0065 | 68.7 | 2.2 | 3.5 | 1.8 | 6.8 | 5.2 | 5.1 | ASCENT | 430 | 8

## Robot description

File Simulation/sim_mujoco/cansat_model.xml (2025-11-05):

<mujoco model="CanSatSolidChute">
  <compiler angle="degree" coordinate="local" inertiafromgeom="true"/>
  <option integrator="RK4" gravity="0 0 -9.81"/>

  <visual>
    <map znear="0.001"/>
    <quality shadowsize="4096"/>
  </visual>
  
  <asset>
    <texture type="skybox" builtin="gradient" rgb1="0.3 0.5 0.8" rgb2="0.1 0.2 0.4" width="512" height="3072"/>
    <material name="cansat_frame" shininess="0.7" specular="0.8" rgba="0.8 0.2 0.2 1"/>
    <material name="parachute_fabric" shininess="0.1" specular="0.1" rgba="0.95 0.95 0.95 0.9"/>
  </asset>

  <worldbody>
    <geom name="ground" type="plane" size="2000 2000 0.1" rgba="0.2 0.3 0.2 1"/>
    <light name="sun" directional="true" pos="0 -1 2" dir="0 1 -1" castshadow="true"/>

    <body name="cansat_body" pos="0 0 1000">
      <freejoint name="world_joint"/>
      
      <!-- CanSat "Cage" Frame -->
      <geom material="cansat_frame" type="capsule" fromto="0.075 0 -0.2 0.075 0 0.2" size="0.01"/><geom material="cansat_frame" type="capsule" fromto="-0.075 0 -0.2 -0.075 0 0.2" size="0.01"/><geom material="cansat_frame" type="capsule" fromto="0 0.075 -0.2 0 0.075 0.2" size="0.01"/><geom material="cansat_frame" type="capsule" fromto="0 -0.075 -0.2 0 -0.075 0.2" size="0.01"/><geom material="cansat_frame" type="capsule" fromto="0.075 0 0.2 0.053 0.053 0.2" size="0.01"/><geom material="cansat_frame" type="capsule" fromto="0.053 0.053 0.2 0 0.075 0.2" size="0.01"/><geom material="cansat_frame" type="capsule" fromto="0 0.075 0.2 -0.053 0.053 0.2" size="0.01"/><geom material="cansat_frame" type="capsule" fromto="-0.053 0.053 0.2 -0.075 0 0.2" size="0.01"/><geom material="cansat_frame" type="capsule" fromto="-0.075 0 0.2 -0.053 -0.053 0.2" size="0.01"/><geom material="cansat_frame" type="capsule" fromto="-0.053 -0.053 0.2 0 -0.075 0.2" size="0.01"/><geom material="cansat_frame" type="capsule" fromto="0 -0.075 0.2 0.053 -0.053 0.2" size="0.01"/><geom material="cansat_frame" type="capsule" fromto="0.053 -0.053 0.2 0.075 0 0.2" size="0.01"/><geom material="cansat_frame" type="capsule" fromto="0.075 0 -0.2 0.053 0.053 -0.2" size="0.01"/><geom material="cansat_frame" type="capsule" fromto="0.053 0.053 -0.2 0 0.075 -0.2" size="0.01"/><geom material="cansat_frame" type="capsule" fromto="0 0.075 -0.2 -0.053 0.053 -0.2" size="0.01"/><geom material="cansat_frame" type="capsule" fromto="-0.053 0.053 -0.2 -0.075 0 -0.2" size="0.01"/><geom material="cansat_frame" type="capsule" fromto="-0.075 0 -0.2 -0.053 -0.053 -0.2" size="0.01"/><geom material="cansat_frame" type="capsule" fromto="-0.053 -0.053 -0.2 0 -0.075 -0.2" size="0.01"/><geom material="cansat_frame" type="capsule" fromto="0 -0.075 -0.2 0.053 -0.053 -0.2" size="0.01"/><geom material="cansat_frame" type="capsule" fromto="0.053 -0.053 -0.2 0.075 0 -0.2" size="0.01"/>
      
      <!-- Reaction Wheels -->
      <body name="rw_roll" pos="0 0 -0.1"><joint name="joint_x_roll" type="hinge" axis="1 0 0"/><geom type="cylinder" size="0.05 0.01" rgba="1 0.2 0.2 1"/><geom type="box" size="0.05 0.005 0.005" pos="0.025 0 0" rgba="1 1 1 1"/></body>
      <body name="rw_pitch" pos="0 0 0"><joint name="joint_y_pitch" type="hinge" axis="0 1 0"/><geom type="cylinder" size="0.05 0.01" rgba="0.2 1 0.2 1"/><geom type="box" size="0.05 0.005 0.005" pos="0.025 0 0" rgba="1 1 1 1"/></body>
      <body name="rw_yaw" pos="0 0 0.1"><joint name="joint_z_yaw" type="hinge" axis="0 0 1"/><geom type="cylinder" size="0.05 0.01" rgba="0.2 0.2 1 1"/><geom type="box" size="0.05 0.005 0.005" pos="0.025 0 0" rgba="1 1 1 1"/></body>

      <!-- Solid Parachute model (no spill hole) -->
      <geom name="panel1" material="parachute_fabric" type="capsule" fromto="0.25 0 0.6 0.125 0.216 0.6" size="0.1" contype="0" conaffinity="0" mass="0"/><geom name="panel2" material="parachute_fabric" type="capsule" fromto="0.125 0.216 0.6 -0.125 0.216 0.6" size="0.1" contype="0" conaffinity="0" mass="0"/><geom name="panel3" material="parachute_fabric" type="capsule" fromto="-0.125 0.216 0.6 -0.25 0 0.6" size="0.1" contype="0" conaffinity="0" mass="0"/><geom name="panel4" material="parachute_fabric" type="capsule" fromto="-0.25 0 0.6 -0.125 -0.216 0.6" size="0.1" contype="0" conaffinity="0" mass="0"/><geom name="panel5" material="parachute_fabric" type="capsule" fromto="-0.125 -0.216 0.6 0.125 -0.216 0.6" size="0.1" contype="0" conaffinity="0" mass="0"/><geom name="panel6" material="parachute_fabric" type="capsule" fromto="0.125 -0.216 0.6 0.25 0 0.6" size="0.1" contype="0" conaffinity="0" mass="0"/>
      <!-- FIX: Added a central cylinder to plug the spill hole -->
      <geom name="chute_center_plug" material="parachute_fabric" type="cylinder" pos="0 0 0.6" size="0.13 0.001" contype="0" conaffinity="0" mass="0"/>
      
      <!-- Riser lines -->
      <geom name="riser1" material="parachute_fabric" type="capsule" fromto="0 0 0.2 0.25 0 0.6" size="0.004"/><geom name="riser2" material="parachute_fabric" type="capsule" fromto="0 0 0.2 -0.25 0 0.6" size="0.004"/><geom name="riser3" material="parachute_fabric" type="capsule" fromto="0 0 0.2 -0.125 0.216 0.6" size="0.004"/><geom name="riser4" material="parachute_fabric" type="capsule" fromto="0 0 0.2 0.125 -0.216 0.6" size="0.004"/>
    </body>
  </worldbody>
  
  <actuator>
    <motor name="motor_x_roll" joint="joint_x_roll" gear="1" ctrllimited="true" ctrlrange="-1.0 1.0"/>
    <motor name="motor_y_pitch" joint="joint_y_pitch" gear="1" ctrllimited="true" ctrlrange="-1.0 1.0"/>
    <motor name="motor_z_yaw" joint="joint_z_yaw" gear="1" ctrllimited="true" ctrlrange="-1.0 1.0"/>
  </actuator>
</mujoco>

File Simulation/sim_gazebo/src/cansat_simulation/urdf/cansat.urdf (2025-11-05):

<?xml version="1.0"?>
<robot name="CanSatSolidChute">

  <material name="red">
    <color rgba="0.8 0.2 0.2 1.0"/>
  </material>
  <material name="white">
    <color rgba="0.95 0.95 0.95 0.9"/>
  </material>
  <material name="green">
    <color rgba="0.2 1.0 0.2 1.0"/>
  </material>
  <material name="blue">
    <color rgba="0.2 0.2 1.0 1.0"/>
  </material>

  <link name="base_link">
    <inertial>
      <mass value="0.35"/>
      <inertia ixx="0.001" ixy="0" ixz="0" iyy="0.001" iyz="0" izz="0.0005"/>
    </inertial>
    <visual>
      <geometry>
        <cylinder radius="0.075" length="0.4"/>
      </geometry>
      <material name="red"/>
    </visual>
    <collision>
      <geometry>
        <cylinder radius="0.075" length="0.4"/>
      </geometry>
    </collision>
  </link>

  <link name="parachute_link">
    <inertial>
      <mass value="0.1"/>
      <inertia ixx="1e-3" ixy="0" ixz="0" iyy="1e-3" iyz="0" izz="1e-3"/>
    </inertial>
    <visual>
        <origin rpy="0 0 0"/>
        <geometry>
            <cylinder radius="0.25" length="0.01"/>
        </geometry>
        <material name="white"/>
    </visual>
    <collision>
         <geometry>
            <cylinder radius="0.25" length="0.01"/>
        </geometry>
    </collision>
  </link>
  <joint name="parachute_joint" type="fixed">
    <parent link="base_link"/>
    <child link="parachute_link"/>
    <origin xyz="0 0 0.4"/> </joint>

  <link name="rw_x_link">
    <inertial>
      <mass value="0.05"/>
      <inertia ixx="1e-5" ixy="0" ixz="0" iyy="1e-5" iyz="0" izz="2e-5"/>
    </inertial>
    <visual>
      <geometry><cylinder radius="0.05" length="0.01"/></geometry>
      <material name="red"/>
    </visual>
  </link>
  <joint name="rw_x_joint" type="revolute">
    <parent link="base_link"/>
    <child link="rw_x_link"/>
    <origin xyz="0 0 -0.1" rpy="0 1.5707 0"/> <axis xyz="1 0 0"/>
    <limit effort="1.0" velocity="1000"/>
  </joint>

  <link name="rw_y_link">
    <inertial>
      <mass value="0.05"/>
      <inertia ixx="1e-5" ixy="0" ixz="0" iyy="1e-5" iyz="0" izz="2e-5"/>
    </inertial>
    <visual>
      <geometry><cylinder radius="0.05" length="0.01"/></geometry>
      <material name="green"/>
    </visual>
  </link>
  <joint name="rw_y_joint" type="revolute">
    <parent link="base_link"/>
    <child link="rw_y_link"/>
    <origin xyz="0 0 0" rpy="1.5707 0 0"/> <axis xyz="0 1 0"/>
    <limit effort="1.0" velocity="1000"/>
  </joint>

  <link name="rw_z_link">
    <inertial>
      <mass value="0.05"/>
      <inertia ixx="1e-5" ixy="0" ixz="0" iyy="1e-5" iyz="0" izz="2e-5"/>
    </inertial>
    <visual>
      <geometry><cylinder radius="0.05" length="0.01"/></geometry>
      <material name="blue"/>
    </visual>
  </link>
  <joint name="rw_z_joint" type="revolute">
    <parent link="base_link"/>
    <child link="rw_z_link"/>
    <origin xyz="0 0 0.1"/>
    <axis xyz="0 0 1"/>
    <limit effort="1.0" velocity="1000"/>
  </joint>

  <gazebo reference="base_link"><material>Gazebo/Red</material></gazebo>
  <gazebo reference="parachute_link"><material>Gazebo/White</material></gazebo>
  <gazebo reference="rw_x_link"><material>Gazebo/Red</material></gazebo>
  <gazebo reference="rw_y_link"><material>Gazebo/Green</material></gazebo>
  <gazebo reference="rw_z_link"><material>Gazebo/Blue</material></gazebo>

  <gazebo>
    <plugin name="aerodynamics_plugin" filename="libaerodynamics_plugin.so"/>
  </gazebo>

  <gazebo>
    <plugin name="reaction_wheel_plugin" filename="libreaction_wheel_plugin.so"/>
  </gazebo>

  <gazebo reference="base_link">
    <sensor name="imu_sensor" type="imu">
      <always_on>true</always_on>
      <update_rate>100</update_rate>
      <plugin name="gazebo_ros_imu_sensor" filename="libgazebo_ros_imu_sensor.so">
        <ros><remapping>~/out:=imu</remapping></ros>
      </plugin>
    </sensor>
  </gazebo>

</robot>

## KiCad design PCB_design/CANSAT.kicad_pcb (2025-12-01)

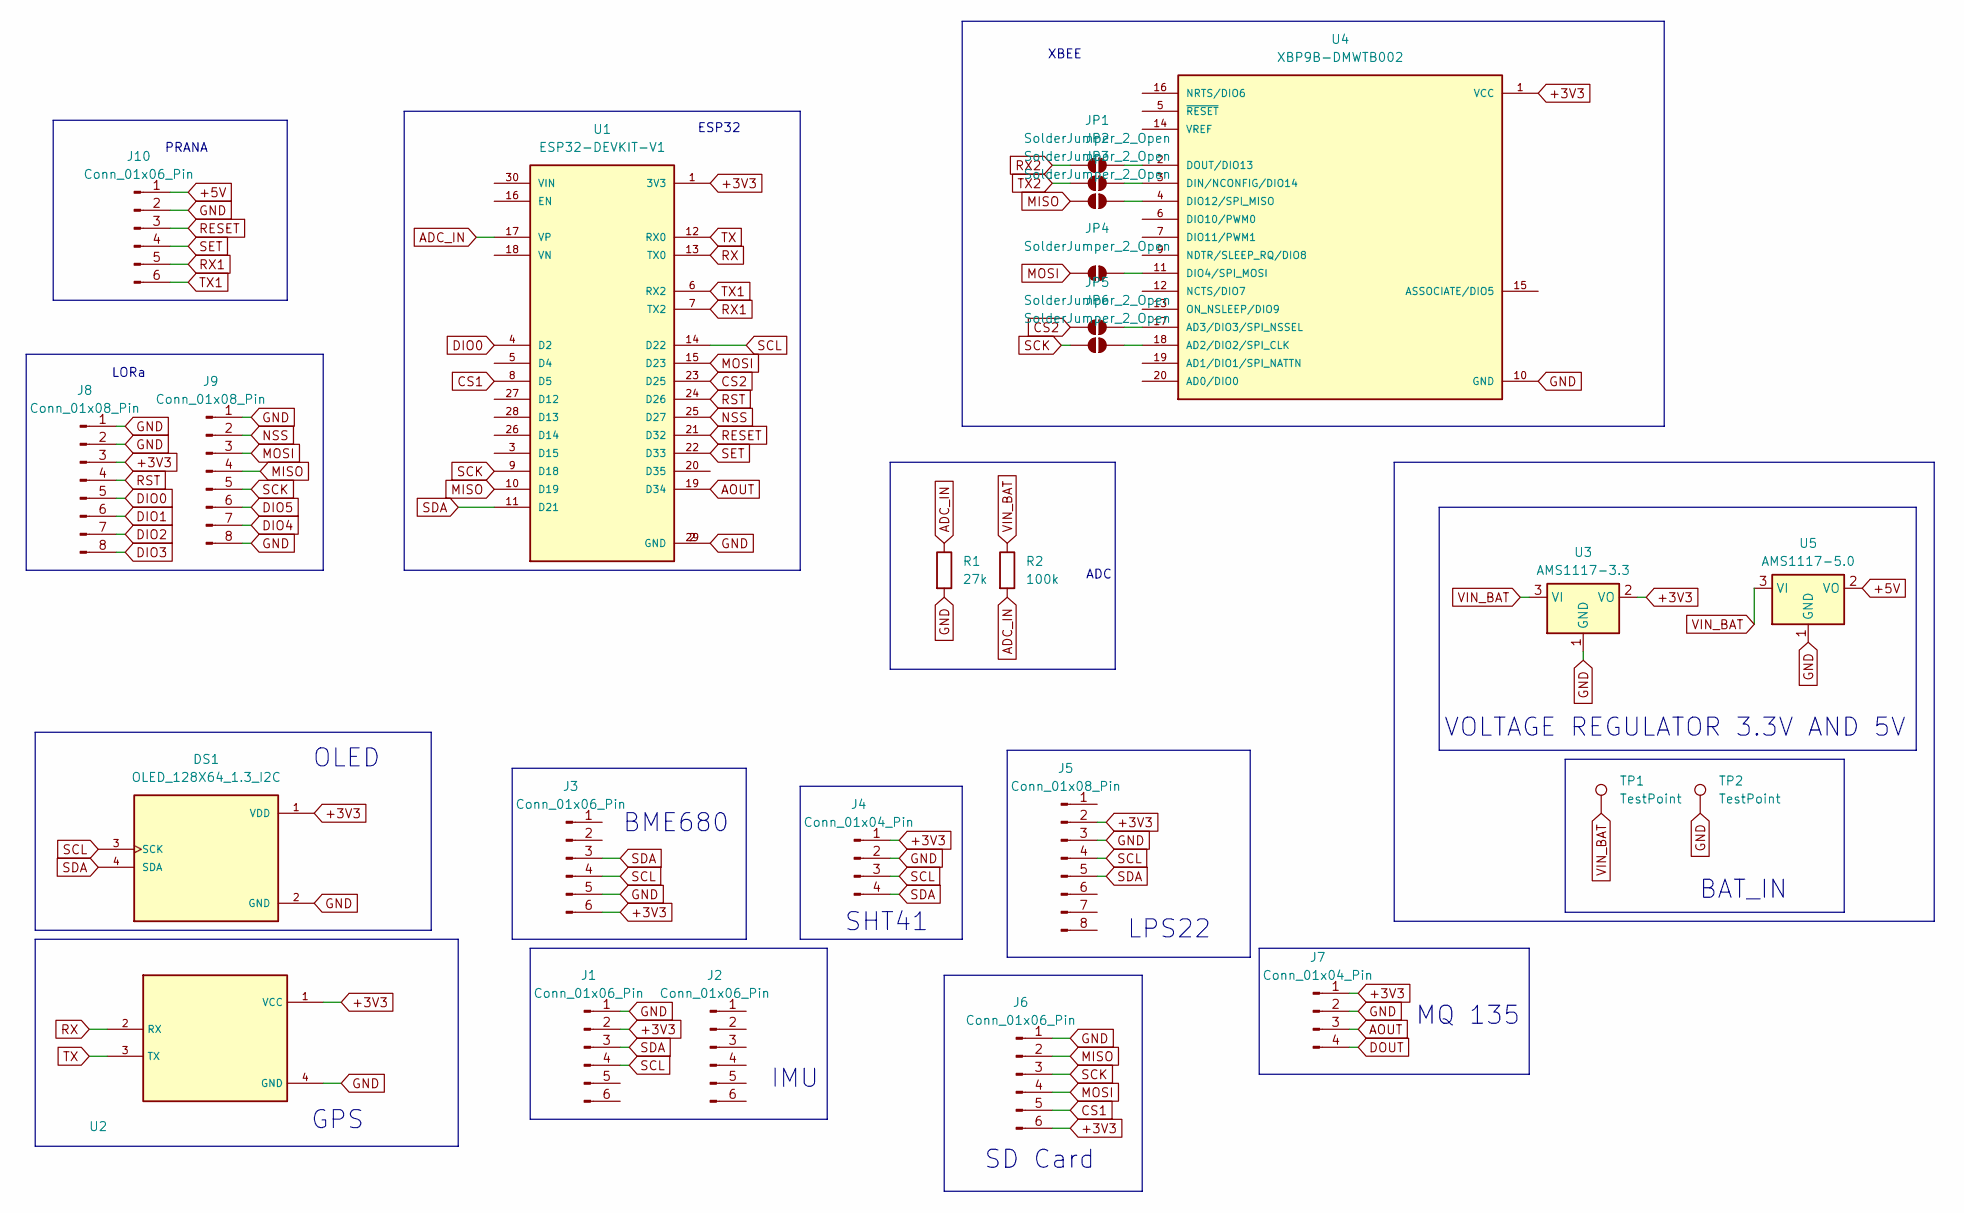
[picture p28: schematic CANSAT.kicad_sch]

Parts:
DS1: OLED_128X64_1.3_I2C; LCD_OLED_128X64_1.3_I2C; PARTREV NA
J1, J2, J3, J6, J10: Conn_01x06_Pin; PinSocket_1x06_P2.54mm_Vertical
J4, J7: Conn_01x04_Pin; PinSocket_1x04_P2.54mm_Vertical
J5, J8, J9: Conn_01x08_Pin; PinHeader_1x08_P2.54mm_Vertical
JP1, JP2, JP3, JP4, JP5, JP6: SolderJumper_2_Open; SolderJumper-2_P1.3mm_Open_TrianglePad1.0x1.5mm
R1: 27k; R_Axial_DIN0411_L9.9mm_D3.6mm_P15.24mm_Horizontal
R2: 100k; R_Axial_DIN0411_L9.9mm_D3.6mm_P15.24mm_Horizontal
TP1, TP2: TestPoint; TestPoint_Pad_4.0x4.0mm
U1: ESP32-DEVKIT-V1; MODULE_ESP32_DEVKIT_V1; PARTREV N/A
U2: NEO_GPS
U3: AMS1117-3.3; SOT-223-3_TabPin2
U4: XBP9B-DMWTB002; DIP2200W51P200L3294H279Q20P
U5: AMS1117-5.0; SOT-223-3_TabPin2

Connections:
+3V3: DS1.1 (VDD), J1.2, J3.6, J4.1, J5.2, J6.6, J7.1, J8.3, U1.1 (3V3), U2.1 (VCC), U3.2 (VO), U4.1 (VCC)
+5V: J10.1, U5.2 (VO)
ADC_IN: R1.1, R2.2, U1.17 (VP)
AOUT: J7.3, U1.19 (D34)
CS1: J6.5, U1.8 (D5)
CS2: JP5.1 (A), U1.23 (D25)
D4: U1.5 (D4); also elsewhere on the board
D12: U1.27 (D12); also elsewhere on the board
D13: U1.28 (D13); also elsewhere on the board
D14: U1.26 (D14); also elsewhere on the board
D15: U1.3 (D15); also elsewhere on the board
DIO0: J8.5, U1.4 (D2)
DIO1: J8.6
DIO2: J8.7
DIO3: J8.8
DIO4: J9.7
DIO5: J9.6
DOUT: J7.4
EN: U1.16 (EN); also elsewhere on the board
GND: DS1.2 (GND), J1.1, J3.5, J4.2, J5.3, J6.1, J7.2, J8.1, J8.2, J9.1, J9.8, J10.2, R1.2, TP2.1, U1.2 (GND), U1.29 (GND), U2.4 (GND), U3.1 (GND), U4.10 (GND), U5.1 (GND)
MISO: J6.2, J9.4, JP3.1 (A), U1.10 (D19)
MOSI: J6.4, J9.3, JP4.1 (A), U1.15 (D23)
NSS: J9.2, U1.25 (D27)
unnamed: JP1.2 (B), U4.2 (DOUT/DIO13)
unnamed: JP2.2 (B), U4.3 (DIN/NCONFIG/DIO14)
unnamed: JP3.2 (B), U4.4 (DIO12/SPI_MISO)
unnamed: JP4.2 (B), U4.11 (DIO4/SPI_MOSI)
unnamed: JP5.2 (B), U4.17 (AD3/DIO3/SPI_NSSEL)
unnamed: JP6.2 (B), U4.18 (AD2/DIO2/SPI_CLK)
RESET: J10.3, U1.21 (D32)
RST: J8.4, U1.24 (D26)
RX: U1.13 (TX0), U2.2 (RX)
RX1: J10.5, U1.7 (TX2)
RX2: JP1.1 (A)
SCK: J6.3, J9.5, JP6.1 (A), U1.9 (D18)
SCL: DS1.3 (SCK), J1.4, J3.4, J4.3, J5.4, U1.14 (D22)
SDA: DS1.4 (SDA), J1.3, J3.3, J4.4, J5.5, U1.11 (D21)
SET: J10.4, U1.22 (D33)
TX: U1.12 (RX0), U2.3 (TX)
TX1: J10.6, U1.6 (RX2)
TX2: JP2.1 (A)
VIN: U1.30 (VIN); also elsewhere on the board
VIN_BAT: R2.1, TP1.1, U3.3 (VI), U5.3 (VI)
VN: U1.18 (VN); also elsewhere on the board

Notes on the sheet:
OLED
SD Card
BAT_IN
LPS22
XBEE
ESP32
SHT41
IMU
GPS
VOLTAGE REGULATOR 3.3V AND 5V
ADC
PRANA
BME680
LORa
MQ 135

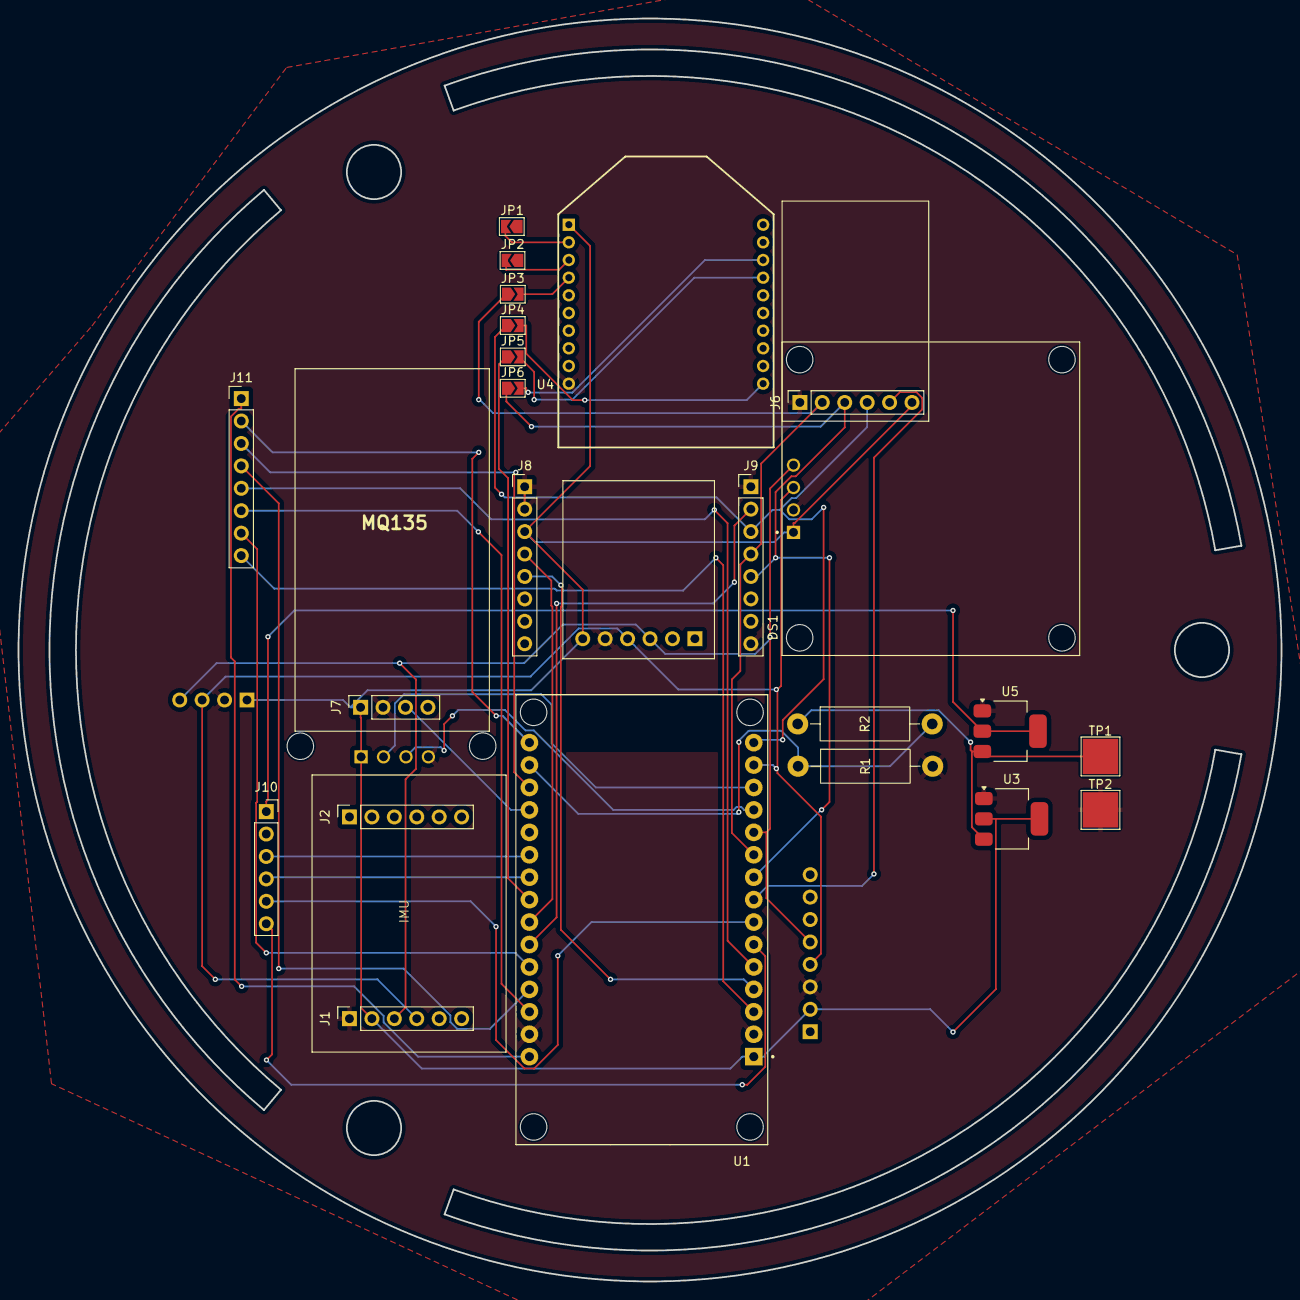
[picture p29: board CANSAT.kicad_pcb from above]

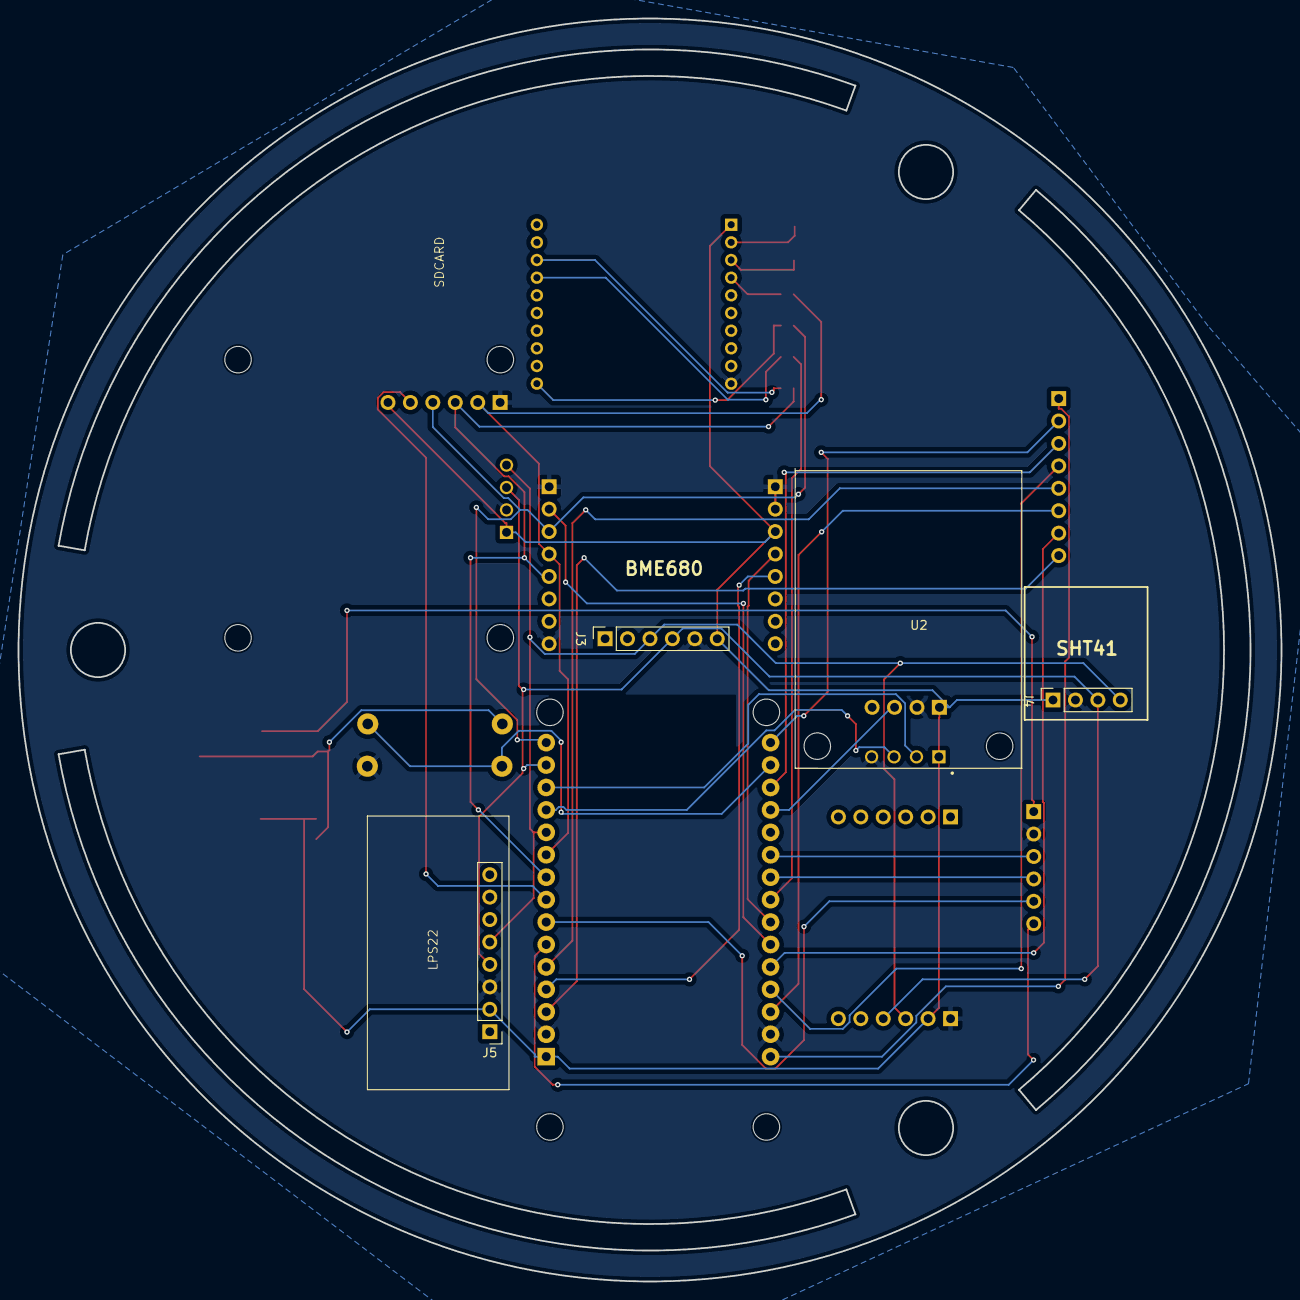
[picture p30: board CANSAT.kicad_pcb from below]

Board: 2 copper layers, 143.0 x 143.0 mm, 27 parts (4 on the bottom side), 36 nets.

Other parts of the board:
J11: Conn_01x08_Pin; PinHeader_1x08_P2.54mm_Vertical

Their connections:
D4: J11.5; also elsewhere on the board
D12: J11.4; also elsewhere on the board
D13: J11.6; also elsewhere on the board
D14: J11.7; also elsewhere on the board
D15: J11.8; also elsewhere on the board
EN: J11.2; also elsewhere on the board
VIN: J11.1; also elsewhere on the board
VN: J11.3; also elsewhere on the board

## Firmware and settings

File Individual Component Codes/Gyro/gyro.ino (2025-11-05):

#include <Wire.h>
#include "ICM_20948.h" // IMU Library
#include <math.h>     // Required for atan2 and sqrt

// I2C Address for the sensor
#define AD0_VAL 1

// I2C pins for IMU (ICM-20948)
#define I2C_SDA 21 
#define I2C_SCL 22 

ICM_20948_I2C myIMU; // Create an ICM_20948_I2C object

// --- Slew Rate Limiter Class ---
// This class limits the rate of change of a signal.
class SlewRateLimiter {
public:
  // Constructor: Initializes the limiter with a maximum rate of change.
  // maxRate: The maximum change in output units per second (e.g., PWM units/sec).
  SlewRateLimiter(double maxRate) {
    _maxRateOfChange = maxRate;
    _previousOutput = 0.0;
    _previousTime = micros(); // Use micros() for higher resolution
  }

  // Calculates the next rate-limited output value.
  // input: The raw, unlimited input value from the PID controller.
  // returns: The new output value, ramped if necessary.
  double calculate(double input) {
    unsigned long currentTime = micros();
    double elapsedTime = (double)(currentTime - _previousTime) / 1000000.0; // in seconds
    _previousTime = currentTime;

    // Calculate the maximum allowed change for this time interval
    double maxDelta = _maxRateOfChange * elapsedTime;

    // Calculate the desired change
    double delta = input - _previousOutput;

    // Constrain the change to the maximum allowed rate
    if (delta > maxDelta) {
      delta = maxDelta;
    } else if (delta < -maxDelta) {
      delta = -maxDelta;
    }

    // Apply the limited change to the previous output
    _previousOutput += delta;
    
    return _previousOutput;
  }
  
  // Resets the limiter's state to a specific value.
  void reset(double value) {
    _previousOutput = value;
    _previousTime = micros();
  }

private:
  double _maxRateOfChange;
  double _previousOutput;
  unsigned long _previousTime;
};

// --- Motor Dead-Zone Configuration ---
// This is the minimum speed threshold to overcome motor stiction.
#define DEAD_ZONE_THRESHOLD 38 // Approx 15% of 255

// --- Motor Pin Assignments ---
#define M1_IN1 34
#define M1_IN2 35
#define M1_PWM 32
#define M2_IN1 19
#define M2_IN2 18
#define M2_PWM 5
#define M3_IN1 2
#define M3_IN2 15
#define M3_PWM 4

const int M1_PWM_CHANNEL = 0, M2_PWM_CHANNEL = 1, M3_PWM_CHANNEL = 2;
const int PWM_FREQ = 5000, PWM_RESOLUTION = 8;

// --- PID Controller Variables ---
double Kp = 10.0, Ki = 0.1, Kd = 0.8; // You MUST re-tune these values!
double pitch_setpoint = 0.0, roll_setpoint = 0.0;
double pitch_error, roll_error, prev_pitch_error = 0, prev_roll_error = 0;
double pitch_integral = 0, roll_integral = 0;
double pitch_derivative, roll_derivative;
unsigned long lastTime = 0;
double elapsedTime;

// --- Slew Rate Limiter Configuration ---
#define MAX_RATE_OF_CHANGE 20.0 // PWM units per second. TUNE THIS VALUE!
SlewRateLimiter pitchLimiter(MAX_RATE_OF_CHANGE);
SlewRateLimiter rollLimiter(MAX_RATE_OF_CHANGE);

// --- NEW: Reversal Delay State Management ---
// This structure holds the state for the reversal delay logic for a single motor.
struct MotorControlState {
  int lastDirection = 0; // 0: stopped, 1: forward, -1: backward
  unsigned long reversalTimestamp = 0;
  bool delayActive = false;
};

MotorControlState pitchMotorState;
MotorControlState rollMotorState;

// Forward declaration of functions
void setMotorSpeed(int motor, int speed);
int getDelayedSpeed(int targetSpeed, MotorControlState &state);

// --- Dead-Zone Application Function ---
int applyDeadZone(int speed, int threshold) {
  if (speed == 0) {
    return 0;
  }
  if (abs(speed) < threshold) {
    return (speed > 0) ? threshold : -threshold;
  }
  return speed;
}

// --- MOTOR TEST FUNCTION (Unchanged) ---
void testMotors() {
  Serial.println("\n--- Starting Motor Test ---");
  const int testSpeed = 180;
  const int testDelay = 500;
  const int pauseDelay = 250;
  delay(1000);
  Serial.println("Testing Motor 1: Forward..."); setMotorSpeed(1, testSpeed); delay(testDelay);
  Serial.println("Testing Motor 1: Backward..."); setMotorSpeed(1, -testSpeed); delay(testDelay);
  setMotorSpeed(1, 0); delay(pauseDelay);
  Serial.println("Testing Motor 2: Forward..."); setMotorSpeed(2, testSpeed); delay(testDelay);
  Serial.println("Testing Motor 2: Backward..."); setMotorSpeed(2, -testSpeed); delay(testDelay);
  setMotorSpeed(2, 0); delay(pauseDelay);
  Serial.println("Testing Motor 3: Forward..."); setMotorSpeed(3, testSpeed); delay(testDelay);
  Serial.println("Testing Motor 3: Backward..."); setMotorSpeed(3, -testSpeed); delay(testDelay);
  setMotorSpeed(3, 0); delay(pauseDelay);
  Serial.println("--- Motor Test Complete ---\n");
  delay(1000);
}


void setup() {
  Serial.begin(115200);
  while (!Serial) { delay(10); }

  Wire.begin(I2C_SDA, I2C_SCL);
  Wire.setClock(400000);

  Serial.println("Attempting to connect to ICM20948...");
  bool initialized = false;
  while (!initialized) {
    myIMU.begin(Wire, AD0_VAL);
    if (myIMU.status!= ICM_20948_Stat_Ok) {
      Serial.print("!!! ICM20948 CONNECTION FAILED: ");
      Serial.println(myIMU.statusString());
      delay(500);
    } else {
      initialized = true;
    }
  }
  Serial.println("ICM20948 connection successful.");

  // --- Configure Motors & PWM ---
  pinMode(M1_IN1, OUTPUT); pinMode(M1_IN2, OUTPUT);
  pinMode(M2_IN1, OUTPUT); pinMode(M2_IN2, OUTPUT);
  pinMode(M3_IN1, OUTPUT); pinMode(M3_IN2, OUTPUT);

  // --- NEW PWM SETUP for ESP32 Core v3.x ---
  ledcAttachChannel(M1_PWM, PWM_FREQ, PWM_RESOLUTION, M1_PWM_CHANNEL);
  ledcAttachChannel(M2_PWM, PWM_FREQ, PWM_RESOLUTION, M2_PWM_CHANNEL);
  ledcAttachChannel(M3_PWM, PWM_FREQ, PWM_RESOLUTION, M3_PWM_CHANNEL);

  lastTime = millis();
  Serial.println("Initialization complete. Starting control loop.");
}

void loop() {
  if (myIMU.dataReady()) {
    myIMU.getAGMT();

    // --- Time Calculation ---
    unsigned long currentTime = millis();
    elapsedTime = (double)(currentTime - lastTime) / 1000.0;
    lastTime = currentTime;

    // --- Pitch & Roll Calculation (from Accelerometer data) ---
    float ax = myIMU.accX();
    float ay = myIMU.accY();
    float az = myIMU.accZ();
    float current_pitch = atan2(-ax, sqrt(ay * ay + az * az)) * 180.0 / M_PI;
    float current_roll  = atan2(ay, az) * 180.0 / M_PI;

    // --- PID Calculations (Raw Output) ---
    pitch_error = pitch_setpoint - current_pitch;
    roll_error = roll_setpoint - current_roll;
    pitch_integral += pitch_error * elapsedTime;
    roll_integral += roll_error * elapsedTime;
    pitch_derivative = (pitch_error - prev_pitch_error) / elapsedTime;
    roll_derivative = (roll_error - prev_roll_error) / elapsedTime;
    
    double raw_pitch_output = (Kp * pitch_error) + (Ki * pitch_integral) + (Kd * pitch_derivative);
    double raw_roll_output = (Kp * roll_error) + (Ki * roll_integral) + (Kd * roll_derivative);
    
    prev_pitch_error = pitch_error;
    prev_roll_error = roll_error;

    // --- Apply Slew Rate Limiting ---
    double limited_pitch_output = pitchLimiter.calculate(raw_pitch_output);
    double limited_roll_output = rollLimiter.calculate(raw_roll_output);

    // Constrain the output to the PWM range
    int motor_pitch_speed = constrain(limited_pitch_output, -255, 255);
    int motor_roll_speed = constrain(limited_roll_output, -255, 255);

    // --- NEW: Apply Directional Reversal Delay ---
    int delayed_pitch_speed = getDelayedSpeed(motor_pitch_speed, pitchMotorState);
    int delayed_roll_speed = getDelayedSpeed(motor_roll_speed, rollMotorState);

    // --- Apply Dead Zone / Minimum Speed ---
    int final_pitch_speed = applyDeadZone(delayed_pitch_speed, DEAD_ZONE_THRESHOLD);
    int final_roll_speed = applyDeadZone(delayed_roll_speed, DEAD_ZONE_THRESHOLD);

    // --- Motor Control ---
    setMotorSpeed(1, final_pitch_speed);
    setMotorSpeed(2, final_roll_speed);
    setMotorSpeed(3, 0); 
    
    // --- Serial Output ---
    Serial.print("Pitch: "); Serial.print(current_pitch, 2);
    Serial.print(" | Roll: "); Serial.print(current_roll, 2);
    Serial.print(" | P_Out: "); Serial.print(final_pitch_speed);
    Serial.print(" | R_Out: "); Serial.println(final_roll_speed);
  }
}

// --- NEW: Reversal Delay Logic ---
// This function enforces a delay when motor direction is reversed.
int getDelayedSpeed(int targetSpeed, MotorControlState &state) {
    // Determine the direction of the new command
    int newDirection = 0;
    if (targetSpeed > 0) newDirection = 1;
    else if (targetSpeed < 0) newDirection = -1;

    // Check if a reversal is being commanded.
    // A reversal occurs if we change from forward to backward (1 to -1), or vice-versa.
    if (newDirection != 0 && newDirection != state.lastDirection && state.lastDirection != 0) {
        // If a delay is not already active, start one.
        if (!state.delayActive) {
            state.delayActive = true;
            state.reversalTimestamp = millis();
        }
    }

    // If a delay is active, check if it should end.
    if (state.delayActive) {
        unsigned long timeSinceReversal = millis() - state.reversalTimestamp;
        // Conditions to end the delay: 2 seconds have passed AND the new command is strong enough.
        if (timeSinceReversal > 2000 && abs(targetSpeed) > DEAD_ZONE_THRESHOLD) {
            state.delayActive = false; // End the delay
        } else {
            // Delay is still active, command the motor to stop.
            state.lastDirection = 0; // We are actively holding it at zero
            return 0;
        }
    }

    // If we reach here, the delay is not active. The motor can move.
    state.lastDirection = newDirection;
    return targetSpeed;
}

// --- MOTOR SPEED FUNCTION (Updated for ESP32 Core v3.x) ---
void setMotorSpeed(int motor, int speed) {
  int pwmVal = abs(speed);
  if (pwmVal > 255) pwmVal = 255; 
  switch (motor) {
    case 1:
      if (speed > 0) { digitalWrite(M1_IN1, HIGH); digitalWrite(M1_IN2, LOW); } else if (speed < 0) { digitalWrite(M1_IN1, LOW); digitalWrite(M1_IN2, HIGH); } else { digitalWrite(M1_IN1, LOW); digitalWrite(M1_IN2, LOW); }
      ledcWrite(M1_PWM_CHANNEL, pwmVal); break;
    case 2:
      if (speed > 0) { digitalWrite(M2_IN1, HIGH); digitalWrite(M2_IN2, LOW); } else if (speed < 0) { digitalWrite(M2_IN1, LOW); digitalWrite(M2_IN2, HIGH); } else { digitalWrite(M2_IN1, LOW); digitalWrite(M2_IN2, LOW); }
      ledcWrite(M2_PWM_CHANNEL, pwmVal); break;
    case 3:
      if (speed > 0) { digitalWrite(M3_IN1, HIGH); digitalWrite(M3_IN2, LOW); } else if (speed < 0) { digitalWrite(M3_IN1, LOW); digitalWrite(M3_IN2, HIGH); } else { digitalWrite(M3_IN1, LOW); digitalWrite(M3_IN2, LOW); }
      ledcWrite(M3_PWM_CHANNEL, pwmVal); break;
  }
}

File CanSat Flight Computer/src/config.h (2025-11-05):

#ifndef CONFIG_H
#define CONFIG_H

#include <Arduino.h>
#include <LoRa.h>
#include <Preferences.h>

// --- Team Configuration ---
#define TEAM_ID "2024ASI-CANSAT-044"
#define SEALEVELPRESSURE_HPA 1013.25

// --- Pin Definitions ---
#define LORA_SS_PIN 5
#define LORA_RST_PIN 14
#define LORA_DIO0_PIN 2
#define GPS_RX_PIN 16
#define GPS_TX_PIN 17
#define SERVO_PIN 13
#define VOLTAGE_PIN 34
#define SD_CS_PIN 15

// --- I2C Addresses ---
#define LPS22_ADDR 0x5D
#define BME680_ADDR 0x76
#define ICM_ADDR 0x69
#define OLED_ADDR 0x3C

// --- Gas Sensor Pins ---
#define MQ135_PIN 35       // CO2/Air quality sensor
#define MQ5_PIN 39         // LPG/Natural gas sensor

// --- Servo Configuration ---
#define SERVO_NEUTRAL_ANGLE 90
#define SERVO_DEPLOY_ANGLE 0
#define SERVO_RELEASE_ANGLE 180

// --- Battery Configuration ---
#define VOLTAGE_DIVIDER_RATIO 2.0
#define BATTERY_MAX_VOLTAGE 4.2
#define BATTERY_MIN_VOLTAGE 3.0

// --- Flight Parameters ---
#define LAUNCH_ACCEL_THRESHOLD 2.5  // g's
#define APOGEE_DESCENT_THRESHOLD -5.0 // m/s
#define IMPACT_ALTITUDE_THRESHOLD 5.0 // meters AGL
#define IMPACT_VELOCITY_THRESHOLD 2.0 // m/s
#define DEPLOY_ALTITUDE 400.0 // meters AGL
#define AEROBRAKE_RELEASE_ALTITUDE 50.0 // meters AGL

// --- Timing Configuration ---
#define TELEMETRY_INTERVAL 1000 // ms (1 Hz)
#define SENSOR_READ_INTERVAL 100 // ms (10 Hz)
#define SD_FLUSH_INTERVAL 5000 // ms

// --- Flight State Enum ---
enum FlightState : uint8_t {
    BOOT = 0,
    TEST_MODE = 1,
    LAUNCH_PAD = 2,
    ASCENT = 3,
    ROCKET_DEPLOY = 4,
    DESCENT = 5,
    AEROBRAKE_RELEASE = 6,
    IMPACT = 7
};

// --- GPS Serial ---
#define GPS_SERIAL Serial2

// --- Logging Function Declaration ---
void logEvent(const String& message);

#endif

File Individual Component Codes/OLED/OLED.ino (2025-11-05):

// TESTED
// Displays an image, a loading animation, then a live data dashboard.

#include <Wire.h>
#include <Adafruit_GFX.h>
#include <Adafruit_SSD1306.h>

// Screen dimensions
#define SCREEN_WIDTH 128
#define SCREEN_HEIGHT 64

// OLED display I2C address (try 0x3D if 0x3C doesn't work)
#define I2C_ADDRESS 0x3C

// OLED display reset pin (-1 since it shares the ESP32's reset pin)
#define OLED_RESET -1

// Create the display object
Adafruit_SSD1306 display(SCREEN_WIDTH, SCREEN_HEIGHT, &Wire, OLED_RESET);

// --- Static Bitmap Image (128x64) ---
const unsigned char epd_bitmap_Screenshot_2025_09_27_at_2[] PROGMEM = {
    0xff, 0xff, 0xff, 0xff, 0xfe, 0x00, 0x00, 0x00, 0x00, 0x00, 0x00, 0x7f, 0xff, 0xff, 0xff, 0xff,
    0xff, 0xff, 0xff, 0xff, 0xfe, 0x00, 0x00, 0x00, 0x00, 0x00, 0x00, 0x7f, 0xff, 0xff, 0xff, 0xff,
    0xff, 0xff, 0xff, 0xff, 0xfe, 0x00, 0x00, 0x80, 0x00, 0x00, 0x00, 0x7f, 0xff, 0xff, 0xff, 0xff,
    0xff, 0xff, 0xff, 0xff, 0xfe, 0x00, 0x01, 0x00, 0x00, 0x00, 0x00, 0x7f, 0xff, 0xff, 0xff, 0xff,
    0xff, 0xff, 0xff, 0xff, 0xfe, 0x00, 0x01, 0x00, 0x00, 0x00, 0x00, 0x7f, 0xff, 0xff, 0xff, 0xff,
    0xff, 0xff, 0xff, 0xff, 0xfe, 0x06, 0x00, 0x00, 0x00, 0x00, 0x00, 0x7f, 0xff, 0xff, 0xff, 0xff,
    0xff, 0xff, 0xff, 0xff, 0xfe, 0x0c, 0x00, 0x00, 0x00, 0x00, 0x00, 0x7f, 0xff, 0xff, 0xff, 0xff,
    0xff, 0xff, 0xff, 0xff, 0xfe, 0x0c, 0x00, 0x00, 0x00, 0x00, 0x00, 0x7f, 0xff, 0xff, 0xff, 0xff,
    0xff, 0xff, 0xff, 0xff, 0xfe, 0x00, 0x80, 0x40, 0x00, 0x00, 0x00, 0x7f, 0xff, 0xff, 0xff, 0xff,
    0xff, 0xff, 0xff, 0xff, 0xfe, 0x00, 0x00, 0x00, 0x00, 0x00, 0x00, 0x7f, 0xff, 0xff, 0xff, 0xff,
    0xff, 0xff, 0xff, 0xff, 0xfe, 0x00, 0x80, 0x00, 0x00, 0x00, 0x00, 0x7f, 0xff, 0xff, 0xff, 0xff,
    0xff, 0xff, 0xff, 0xff, 0xff, 0x80, 0x00, 0x00, 0x00, 0x00, 0x00, 0x7f, 0xff, 0xff, 0xff, 0xff,
    0xff, 0xff, 0xff, 0xff, 0xff, 0xf0, 0x00, 0xf8, 0x00, 0x00, 0x00, 0x7f, 0xff, 0xff, 0xff, 0xff,
    0xff, 0xff, 0xff, 0xff, 0xff, 0xfe, 0x07, 0xff, 0x60, 0x00, 0x00, 0xff, 0xff, 0xff, 0xff, 0xff,
    0xff, 0xff, 0xff, 0xff, 0xff, 0xff, 0x9f, 0xff, 0xf0, 0x00, 0x00, 0x7f, 0xff, 0xff, 0xff, 0xff,
    0xff, 0xff, 0xff, 0xff, 0xff, 0xff, 0x07, 0xff, 0xfc, 0x00, 0x00, 0x7f, 0xff, 0xff, 0xff, 0xff,
    0xff, 0xff, 0xff, 0xff, 0xff, 0xfe, 0x01, 0xff, 0xff, 0x00, 0x00, 0x7f, 0xff, 0xff, 0xff, 0xff,
    0xff, 0xff, 0xff, 0xff, 0xff, 0xfc, 0x00, 0x7f, 0xff, 0x80, 0x00, 0x7f, 0xff, 0xff, 0xff, 0xff,
    0xff, 0xff, 0xff, 0xff, 0xff, 0xf8, 0x00, 0x7f, 0xff, 0xf0, 0x00, 0x7f, 0xff, 0xff, 0xff, 0xff,
    0xff, 0xff, 0xff, 0xff, 0xff, 0xf0, 0x00, 0x3f, 0xff, 0xf0, 0x00, 0x7f, 0xff, 0xff, 0xff, 0xff,
    0xff, 0xff, 0xff, 0xff, 0xff, 0xf1, 0x80, 0x3f, 0xff, 0xf0, 0x00, 0x7f, 0xff, 0xff, 0xff, 0xff,
    0xff, 0xff, 0xff, 0xff, 0xff, 0xf3, 0x00, 0x3f, 0xff, 0xfc, 0x00, 0x7f, 0xff, 0xff, 0xff, 0xff,
    0xff, 0xff, 0xff, 0xff, 0xff, 0xf0, 0x00, 0x3f, 0xfe, 0xd8, 0x00, 0x7f, 0xff, 0xff, 0xff, 0xff,
    0xff, 0xff, 0xff, 0xff, 0xff, 0xf0, 0x00, 0x3f, 0xf8, 0x00, 0x00, 0x7f, 0xff, 0xff, 0xff, 0xff,
    0xff, 0xff, 0xff, 0xff, 0xff, 0xf0, 0x00, 0x7f, 0xe0, 0x00, 0x00, 0x7f, 0xff, 0xff, 0xff, 0xff,
    0xff, 0xff, 0xff, 0xff, 0xff, 0xf0, 0x00, 0xff, 0xc0, 0x00, 0x00, 0x7f, 0xff, 0xff, 0xff, 0xff,
    0xff, 0xff, 0xff, 0xff, 0xff, 0xfe, 0x01, 0xff, 0xc0, 0x00, 0x00, 0x7f, 0xff, 0xff, 0xff, 0xff,
    0xff, 0xff, 0xff, 0xff, 0xff, 0xff, 0x83, 0xff, 0x80, 0x00, 0x01, 0x7f, 0xff, 0xff, 0xff, 0xff,
    0xff, 0xff, 0xff, 0xff, 0xff, 0xff, 0xff, 0xff, 0x80, 0x00, 0x02, 0x7f, 0xff, 0xff, 0xff, 0xff,
    0xff, 0xff, 0xff, 0xff, 0xff, 0xff, 0xff, 0xff, 0x80, 0x00, 0x04, 0x7f, 0xff, 0xff, 0xff, 0xff,
    0xff, 0xff, 0xff, 0xff, 0xff, 0xff, 0xff, 0xff, 0x80, 0x30, 0x22, 0x7f, 0xff, 0xff, 0xff, 0xff,
    0xff, 0xff, 0xff, 0xff, 0xff, 0xff, 0xf0, 0xff, 0x80, 0x30, 0x40, 0x7f, 0xff, 0xff, 0xff, 0xff,
    0xff, 0xff, 0xff, 0xff, 0xff, 0xff, 0xc0, 0x1f, 0x80, 0x00, 0xc0, 0xff, 0xff, 0xff, 0xff, 0xff,
    0xff, 0xff, 0xff, 0xff, 0xff, 0xff, 0x80, 0x07, 0xc0, 0x00, 0xc0, 0x7f, 0xff, 0xff, 0xff, 0xff,
    0xff, 0xff, 0xff, 0xff, 0xff, 0xff, 0x00, 0x03, 0xc0, 0x01, 0xc0, 0xff, 0xff, 0xff, 0xff, 0xff,
    0xff, 0xff, 0xff, 0xff, 0xff, 0xff, 0x00, 0x00, 0xf8, 0x01, 0xe0, 0xff, 0xff, 0xff, 0xff, 0xff,
    0xff, 0xff, 0xff, 0xff, 0xff, 0xff, 0x00, 0x00, 0xfc, 0x03, 0xc1, 0xff, 0xff, 0xff, 0xff, 0xff,
    0xff, 0xff, 0xff, 0xff, 0xff, 0xff, 0x00, 0xfe, 0x3f, 0xff, 0x81, 0xff, 0xff, 0xff, 0xff, 0xff,
    0xff, 0xff, 0xff, 0xff, 0xff, 0xff, 0x01, 0xff, 0xbf, 0xff, 0x03, 0xff, 0xff, 0xff, 0xff, 0xff,
    0xff, 0xff, 0xff, 0xff, 0xff, 0xff, 0x03, 0xff, 0xef, 0xff, 0x01, 0xff, 0xff, 0xff, 0xff, 0xff,
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

// --- Function to display the loading animation ---
void displayLoadingScreen() {
  int centerX = SCREEN_WIDTH / 2;
  int centerY = 26;
  int radius = 18;
  int dotRadius = 3;

  for (int j = 0; j < 2; j++) { // Loop for two rotations
    for (int i = 0; i <= 360; i += 15) {
      float angle = radians(i);
      int dotX = centerX + radius * cos(angle);
      int dotY = centerY + radius * sin(angle);

      display.clearDisplay();

      // Draw the static text "VA"
      display.setTextSize(2);
      display.setTextColor(SSD1306_WHITE);
      display.setCursor(centerX - 12, centerY + radius + 5);
      display.print("VA");

      // Draw the circle and moving dot
      display.drawCircle(centerX, centerY, radius, SSD1306_WHITE);
      display.fillCircle(dotX, dotY, dotRadius, SSD1306_WHITE);
      
      display.display();
      delay(10);
    }
  }
}

void setup() {
  Serial.begin(115200);

  // Initialize the OLED display
  if (!display.begin(SSD1306_SWITCHCAPVCC, I2C_ADDRESS)) {
    Serial.println(F("SSD1306 allocation failed"));
    for (;;);
  }

  // --- Step 1: Show Static Image ---
  display.clearDisplay();
  display.drawBitmap(0, 0, epd_bitmap_Screenshot_2025_09_27_at_2, 128, 64, SSD1306_WHITE);
  display.display();
  delay(3000); // Display for 3 seconds

  // --- Step 2: Show Loading Animation ---
  displayLoadingScreen();
  delay(500); // Pause after animation
}
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

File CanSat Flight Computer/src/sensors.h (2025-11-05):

#ifndef SENSORS_H
#define SENSORS_H

#include <Arduino.h>
#include "config.h"
#include "Telemetry.h"  // Include before using TelemetryData
#include <Adafruit_LPS2X.h>
#include "ICM_20948.h"
#include <TinyGPSPlus.h>
#include "KalmanFilter.h"
#include <ESP32Servo.h>
#include <SPI.h>

// Sensor objects (defined in main)
extern Adafruit_LPS22 lps;
extern Adafruit_BME680 bme;
extern ICM_20948_I2C myICM;
extern TinyGPSPlus gps;
extern Servo parachuteServo;
extern KalmanFilter altitudeKF;
extern SensorFusion sensorFusion;

// Calibration data
struct SensorCalibration {
    float gyro_offset_x = 0.0f;
    float gyro_offset_y = 0.0f;
    float gyro_offset_z = 0.0f;
    float accel_offset_x = 0.0f;
    float accel_offset_y = 0.0f;
    float accel_offset_z = 0.0f;
    bool calibrated = false;
};
extern SensorCalibration sensorCal;

// Sensor status flags
extern bool lps_ok, bme_ok, icm_ok, gps_ok, servo_ok, lora_ok, oled_ok, sdCardOK;

// External data
extern struct TelemetryData telemetryData;
extern float groundAltitude;
extern SemaphoreHandle_t servoMutex;

// ============================================
// Gas Sensor Definitions (merged from GasSensors.h)
// ============================================

// Pin definitions for gas sensors
#define MQ135_PIN 35       // CO2/Air quality sensor
#define MQ5_PIN 39         // LPG/Natural gas sensor

// Calibration constants for MQ135 (CO2 measurement)
#define MQ135_RZERO 76.63f  // Calibrated resistance in clean air
#define MQ135_PARA 116.6020682f
#define MQ135_PARB 2.769034857f
#define MQ135_RL 10.0f     // Load resistance in kOhms

// MQ5 thresholds (raw analog values)
#define MQ5_CLEAN_AIR_VALUE 300    // Typical value in clean air
#define MQ5_GAS_THRESHOLD 600      // Threshold for gas detection

// Gas sensor data structure
struct GasSensorData {
    float co2_ppm = 0.0f;          // CO2 concentration in PPM
    float air_quality = 0.0f;      // Air quality index (0-100)
    int lpg_level = 0;             // LPG level (0-4095 raw, or processed)
    bool gas_detected = false;     // LPG/gas detection flag
    bool sensors_ready = false;    // Warmup complete
    uint32_t warmup_start_time = 0;
};

extern GasSensorData gasSensorData;
extern bool mq135_ok;
extern bool mq5_ok;

// Gas sensor function prototypes
void initializeGasSensors();
float calculateCO2PPM(int analogValue);
float calculateAirQuality(float co2_ppm);
void processMQ5Reading(int analogValue);
void readGasSensors();
String getGasSensorStatus();
void checkGasSafetyAlerts();

/**
 * Initialize all sensors with error handling
 */
void initializeSensors() {
    logEvent("=== Sensor Initialization ===");
    
    // LPS22 Barometric Altimeter
    if (lps.begin_I2C(LPS22_ADDR)) {
        lps.setDataRate(LPS22_RATE_75_HZ);
        lps_ok = true;
        logEvent("✓ LPS22 Altimeter OK");
    } else {
        logEvent("✗ LPS22 FAILED");
    }
    
    // ICM-20948 9-DOF IMU
    myICM.begin(Wire, ICM_ADDR);
    if (myICM.status == ICM_20948_Stat_Ok) {
        // Configure IMU
        ICM_20948_smplrt_t sampleRate;
        sampleRate.a = 9;  // 1.125 kHz / (1 + 9) = 112.5 Hz
        sampleRate.g = 9;
        myICM.setSampleRate(0, sampleRate);
        myICM.setSampleRate(1, sampleRate);
        
        icm_ok = true;
        logEvent("✓ ICM-20948 IMU OK");
    } else {
        logEvent("✗ ICM-20948 FAILED (Status: " + String(myICM.status) + ")");
    }
    
    // LoRa Radio
    LoRa.setPins(LORA_SS_PIN, LORA_RST_PIN, LORA_DIO0_PIN);
    if (LoRa.begin(433E6)) {
        LoRa.setSpreadingFactor(7);
        LoRa.setSignalBandwidth(125E3);
        LoRa.setCodingRate4(5);
        LoRa.enableCrc();
        lora_ok = true;
        logEvent("✓ LoRa Radio OK (433 MHz)");
    } else {
        logEvent("✗ LoRa FAILED");
    }
    
    // GPS Module
    GPS_SERIAL.begin(9600, SERIAL_8N1, GPS_RX_PIN, GPS_TX_PIN);
    gps_ok = true;
    logEvent("✓ GPS Serial Started");
    
    // Parachute Servo
    ESP32PWM::allocateTimer(0);
    parachuteServo.setPeriodHertz(50);
    parachuteServo.attach(SERVO_PIN, 500, 2500);
    parachuteServo.write(SERVO_NEUTRAL_ANGLE);
    servo_ok = true;
    logEvent("✓ Servo OK (Neutral: " + String(SERVO_NEUTRAL_ANGLE) + "°)");

    // Gas Sensors

    initializeGasSensors();
    logEvent("=== Initialization Complete ===");
}

/**
 * Calibrate ground altitude using averaging
 */
void calibrateGroundAltitude() {
    if (!lps_ok) {
        logEvent("Cannot calibrate - LPS22 not available");
        return;
    }
    
    logEvent("Calibrating ground altitude...");
    
    const int samples = 100;
    float total_pressure = 0.0f;
    int valid_samples = 0;
    
    for (int i = 0; i < samples; i++) {
        sensors_event_t p_evt, t_evt;
        if (lps.getEvent(&p_evt, &t_evt)) {
            total_pressure += p_evt.pressure;
            valid_samples++;
        }
        delay(10);
    }
    
    if (valid_samples > 0) {
        float avg_pressure = total_pressure / valid_samples;
        groundAltitude = 44330.0f * (1.0f - pow(avg_pressure / SEALEVELPRESSURE_HPA, 0.1903f));
        altitudeKF.reset();
        logEvent("Ground altitude: " + String(groundAltitude, 2) + " m (from " + 
                 String(valid_samples) + " samples)");
    } else {
        logEvent("ERROR: No valid pressure readings");
    }
}

/**
 * Calibrate IMU gyroscope and accelerometer offsets
 */
void calibrateIMU() {
    if (!icm_ok) {
        logEvent("Cannot calibrate - ICM-20948 not available");
        return;
    }
    
    logEvent("Calibrating IMU - Keep still for 3 seconds...");
    
    const int samples = 300;
    float gx_sum = 0, gy_sum = 0, gz_sum = 0;
    float ax_sum = 0, ay_sum = 0, az_sum = 0;
    int valid_samples = 0;
    
    for (int i = 0; i < samples; i++) {
        if (myICM.dataReady()) {
            myICM.getAGMT();
            gx_sum += myICM.gyrX();
            gy_sum += myICM.gyrY();
            gz_sum += myICM.gyrZ();
            ax_sum += myICM.accX();
            ay_sum += myICM.accY();
            az_sum += myICM.accZ();
            valid_samples++;
        }
        delay(10);
    }
    
    if (valid_samples > 0) {
        sensorCal.gyro_offset_x = gx_sum / valid_samples;
        sensorCal.gyro_offset_y = gy_sum / valid_samples;
        sensorCal.gyro_offset_z = gz_sum / valid_samples;
        sensorCal.accel_offset_x = ax_sum / valid_samples;
        sensorCal.accel_offset_y = ay_sum / valid_samples;
        sensorCal.accel_offset_z = (az_sum / valid_samples) - 1.0f; // Remove gravity
        sensorCal.calibrated = true;
        
        logEvent("IMU calibrated (" + String(valid_samples) + " samples)");
        logEvent("Gyro offsets: X=" + String(sensorCal.gyro_offset_x, 3) + 
                 " Y=" + String(sensorCal.gyro_offset_y, 3) + 
                 " Z=" + String(sensorCal.gyro_offset_z, 3));
    } else {
        logEvent("ERROR: No valid IMU readings");
    }
}
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

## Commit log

2025-11-05 Added all files
    [cansat.urdf, cansat_model.xml, data_log.csv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]
2025-11-13 Added cad files
    [parachute_compartment_final.step, section_divider_final.step, spacer_final.step]
2025-11-13 Added the Data collection files
    Data collected during CanSat launch.
    [flight_data_20251107_164203.csv]
2025-12-01 Added pcb design files
    [CANSAT-B_Cu.gbr, CANSAT-B_Mask.gbr, CANSAT-B_Paste.gbr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]
2025-12-01 Added mission requirement guidelines
    [flight_data_20251107_164203.csv]
2025-12-01 Added README.md
    [flight_data_20251107_164203.csv]
